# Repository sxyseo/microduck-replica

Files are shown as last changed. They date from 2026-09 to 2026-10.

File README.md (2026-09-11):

# Microduck 复刻

**简体中文** · [English](README.en.md)

> 对 [Pollen Robotics Microduck](https://pollen-robotics.com/microduck/) 的第三方复刻研究。
> 从官方公开的 MJCF 仿真模型反推出**装配图、爆炸图和可直接导入 CAD 的装配体**。

Microduck 是一只 25cm 高、737g 的双足机器鸭，15 个 Dynamixel XL330 舵机（14 个受策略控制），用强化学习走路。
它的**软件开源（Apache-2.0）**。硬件是**部分开源**：

- ✅ **RPI Robot HAT 板完整开源** —— 见 [`pollen-robotics/elec_RPI_Robot_HAT`](https://github.com/pollen-robotics/elec_RPI_Robot_HAT)（Apache-2.0）：
  KiCad 9 工程、Gerber、BOM、贴片坐标、STEP 一应俱全。这块板**不需要自己画**。
- ❌ **`imu_to_dxl` 板未开源** —— 全网无公开工程，本仓库的逆向是目前唯一公开重建。
- ❌ **机械件无可编辑 CAD**、无 BOM、无装配文档。

> 📌 **勘误（2026-09-03）**：本文档此前写作「硬件不开源、没有 PCB 原理图」，**这是错的**。
> 当时只检索了 `pollen-robotics/microduck` 主仓，未翻查该组织下以 `elec_` 开头的硬件仓库。

但官方在 `microduck_rl` 里发布了完整的 **MJCF 仿真模型 + 47 个 STL 网格**。
MJCF 里包含了完整的运动学树：每个零件挂在谁身上、相对位置精确到 0.1mm、
绕哪根轴转、行程多少、质量和惯量张量。

**这些信息足以还原出装配关系。** 本仓库就是把它还原出来的结果。

---

## 交流群

有人在做同样的事，凑了个微信群一起讨论复刻进度、踩过的坑、元件采购。

**一群、二群、三群都已满 200 人**（微信满 200 后无法扫码进），下面是**四群**的码。

<div align="center">
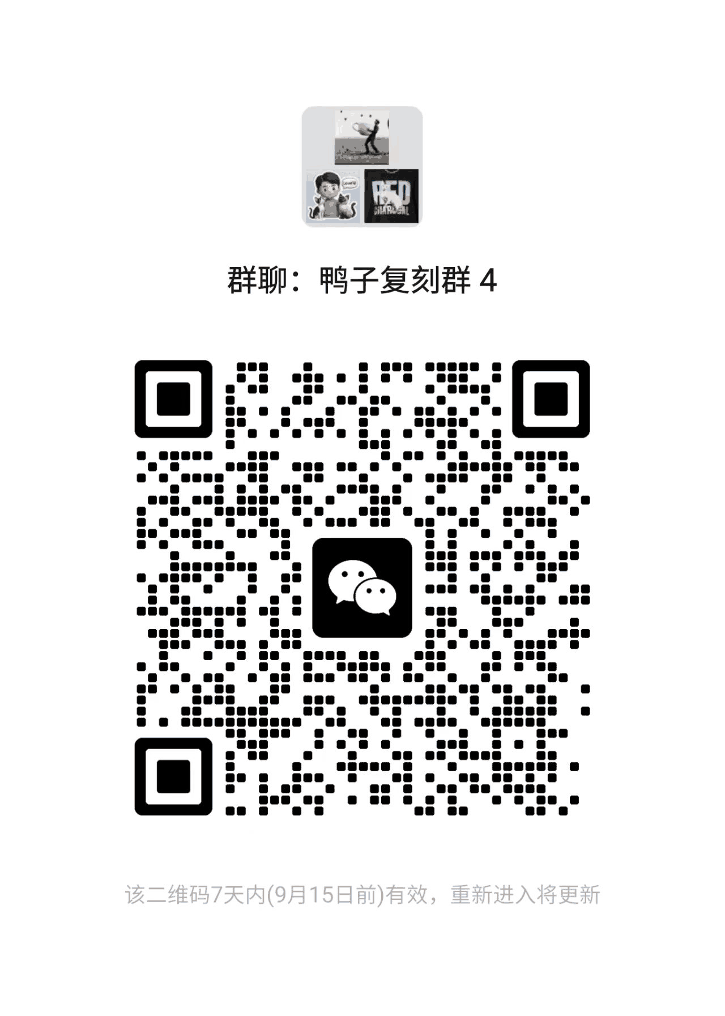
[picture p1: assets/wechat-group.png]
鸭子复刻 微信群
  
  <br>
  <sub><b>鸭子复刻群 4 · 二维码有效期到 2026-09-15</b>（微信群码 7 天自动失效）<br>
  过期了请开个 <a href="https://github.com/fanhao375/microduck-replica/issues">issue</a> 说一声，我会换上新的</sub>
</div>

## 最近更新

<table>
<tr>
<td width="50%" valign="top">

### 🔌 电气 · `imu_to_dxl` PCB 画完了

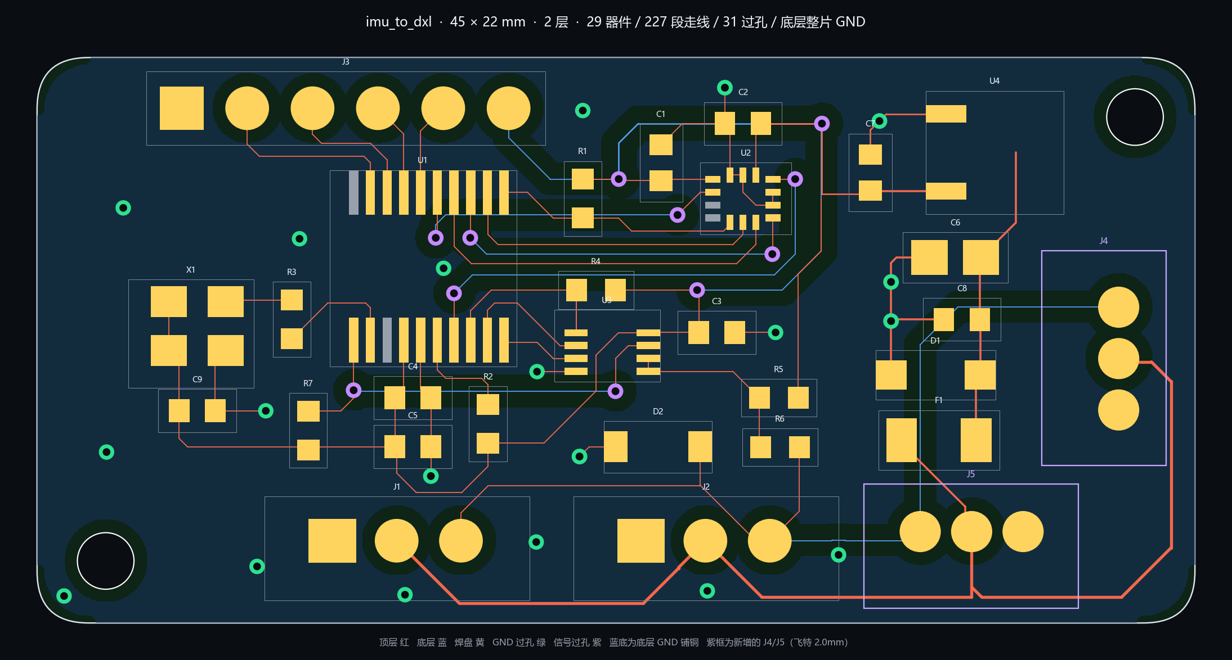
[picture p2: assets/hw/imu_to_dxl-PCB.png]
imu_to_dxl PCB 顶层装配图


官方唯一**没有开源**的那块板，第三方复刻版从原理图一路做到了 PCB。
STM32G031F8P6 + LSM6DSV16X + 半双工缓冲，作为**第 16 个设备**挂在舵机总线上。

**45 × 22 mm，2 层板**，四角 R2 圆角，两个对角 M2 孔；底层整片 GND。
23 个网络全部连通，**DRC 0 违规**，每个芯片电源脚 2.3 mm 内都有去耦。
仍然**没打样、没有实物验证**。

**[设计说明 · 评审要点 · 复查结果](hardware/imu_to_dxl/)**　·　
[原理图 PDF](hardware/imu_to_dxl/imu_to_dxl-原理图.pdf)　·　
[PCB PDF](hardware/imu_to_dxl/imu_to_dxl-PCB.pdf)　·　
[3D STEP](hardware/imu_to_dxl/imu_to_dxl-PCB.step)　·　
[接线表](hardware/imu_to_dxl/imu_to_dxl-接线表.md)　·　
[嘉立创工程](hardware/imu_to_dxl/imu_to_dxl.eprj2)

</td>
<td width="50%" valign="top">

### 🔨 机械 · 首批打印件

<a href="构建日志.md">首批打印件</a>

**有人正在把它真的做出来。** 头壳、躯干壳、腿部结构件和脚已经打印出来，
**腿部件上的 M2 螺丝已经装进去了** —— [紧固件反推](docs/紧固件反推.md)
的结论在实物上成立。

仓库其余部分都是从 MJCF 与源码反推的**纸上分析**，
构建日志记录的是**动手做的过程**：打印参数、装配问题，
以及那些反推数据在实物上到底对不对。

**[构建日志](构建日志.md)**　·　
[打印件清单](print/)　·　
[装配爆炸图](assembly-drawings/)

</td>
</tr>
</table>

> **原理图求评审** —— 特别想听这几处的意见：半双工缓冲的使能逻辑（`2OE` 接常高、
> 发送时有回显 vs 也接 DE、发送时 RX 悬空）；J1/J2 直通的铜皮宽度；
> 不上晶振（TSSOP-20 没引出 `OSC_OUT`，HSI16 跑 1 Mbps 余量够不够）。
> 发现问题请开 [issue](https://github.com/fanhao375/microduck-replica/issues)，或者在上面的群里说。

---

## 🔨 实物进度

> 本仓库反复强调「仿真 STL 不是可打印工程件」。**构建日志就是在验证这句话。**
> 结论会如实记录，无论正反。

**→ [构建日志](构建日志.md)**

---

## 装配爆炸图

爆炸图

`assembly-drawings/` 下共 7 张：

| 文件 | 内容 |
|---|---|
| `01_正面` `02_侧面` `03_背面` `04_四分之三` | 装配完成态，原色 |
| **`05_爆炸图_侧面`** | 15 个部件沿运动链炸开，标注名称与质量 |
| **`06_爆炸图_四分之三`** | 立体视角，可看清左右腿镜像关系 |
| `07_分色对照_装配态` | 与爆炸图同配色的装配完成态，对照用 |

## 装配结构

```
躯干主体 199g
├─ 左髋 yaw→roll 23g → 左髋 roll 6g → 左大腿 48g → 左小腿 22g → 左踝+脚 30g
├─ 颈根 37g → 颈俯仰件 6g → 头 yaw/roll 机构 49g → 头部总成+喙 189g
└─ 右髋 yaw→roll 23g → 右髋 roll 6g → 右大腿 48g → 右小腿 22g → 右踝+脚 30g

整机 737.2g   外形 144 × 141 × 264 mm
```

躯干和头几乎一样重（199g vs 189g）——**头部占整机四分之一，重心很高**，
这解释了为什么它的行走策略难训。

## 关节参数

每条腿 5 个自由度，头颈 4 个 —— **14 个受控**。
整机实际装 **15 个 Dynamixel XL330**：第 15 个驱动喙/下颚，走被动连杆，不进动作空间。

| 关节 | 行程 |
|---|---|
| `hip_yaw` | -25° ~ +30° |
| `hip_roll` | ±22° |
| `hip_pitch` / `knee` / `ankle` / `head_pitch` | ±90° |
| `neck_pitch` | -90° ~ +60° |
| `head_yaw` | ±170° |
| `head_roll` | ±25° |

## 📋 物料清单（BOM）

**要买什么、买几个** —— [`BOM.md`](BOM.md)

整机 15 个舵机、14 个轴承、约 325 件紧固件、2 块要打样的电路板，数量取自上游 MJCF 的
引用计数（38 种网格 / 75 个实例），不是估的。含每块板的器件清单与立创编号。

> ⚠️ 里面有两条会让人买错的更正：**电池是 NP-F550 不是 F970**、**XL330 被超压运行**。

## 3D 打印件

整机全部 STL 单件，按「要打印 / 买现成的」分好类，中英双语命名 —— [`print/`](print/)

| 目录 | 数量 |
|---|---|
| [`print/打印件/`](print/打印件/) | **30 种 / 41 件**结构件 |
| [`print/标准件-无需打印/`](print/标准件-无需打印/) | **9 个**外购件模型（对位用） |

> 上游的 XL330 台架测试夹具在另一个目录，本来就不属于机器人。打印建议与数量表见 [`print/README.md`](print/README.md)，采购见 [机械采购清单](docs/机械采购清单.md)。

## CAD 装配体

`cad/` 下是**已应用世界变换**的 STL —— 直接导入 CAD 就是装好的样子，
不用自己摆位置（上游那 47 个 STL 都是零件自身坐标系的，直接导入会全部堆在原点）。

- `00_Microduck_整机装配体.stl` —— 整机单文件，796792 三角面
- `01` ~ `15` —— 按刚体分组的 15 个部件，文件名即部件名
- `零件对照表.json` —— 每个部件由哪些上游源网格组成

单位 **毫米**。可直接用 FreeCAD / Fusion 360 / SolidWorks / Blender / 各类切片软件打开。

---

## 从运行时反推出的电控方案

<div align="center">
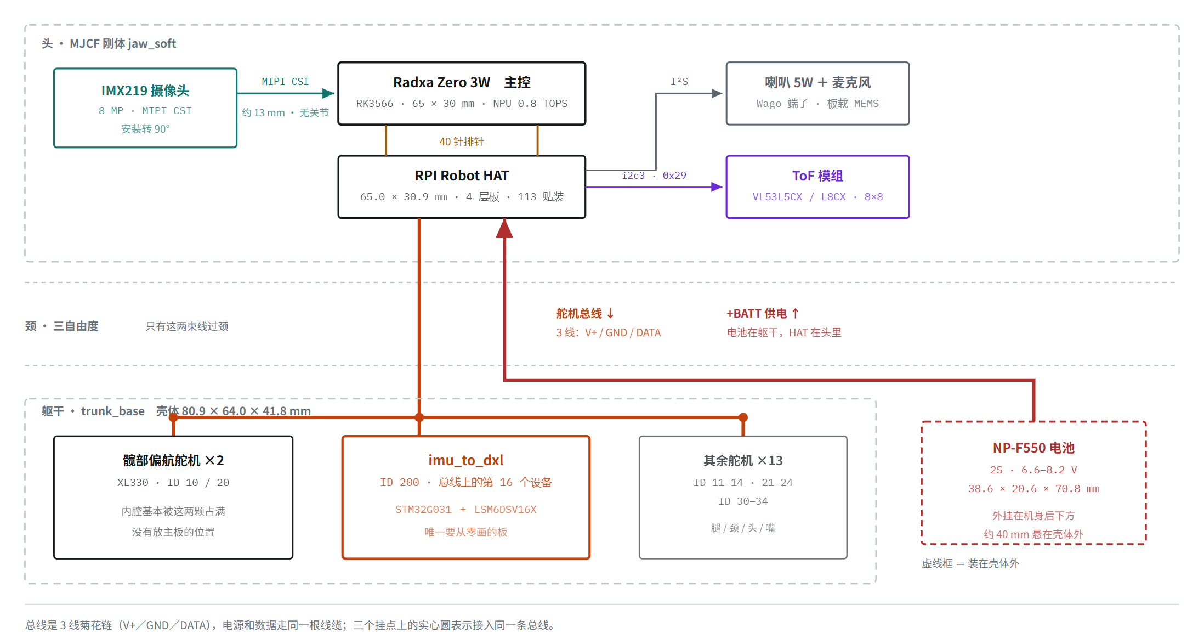
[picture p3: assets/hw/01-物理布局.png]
Microduck 电控总览：板子都装在哪
  
  <br>
  <sub><b>五个模块的物理布局</b> —— 灰色虚线框是物理区域，实线框是模块，红色虚线框表示装在壳体<b>外面</b>。<br>
  <b>橙色</b>是舵机总线（自上而下），<b>红色</b>是电池供电（自下而上）。<br>
  最容易搞错的一条：<b>主控、HAT、摄像头三者都在头里</b>，摄像头距主控板中心约 13 mm 且中间没有关节 ——<br>
  所以 MIPI 排线不穿过脖子，真正过颈的是舵机总线和供电线。<br>
  <a href="docs/硬件入门.md">完整图集与讲解 →</a>　·　<a href="assets/hw/Microduck硬件图集.pdf">下载 PDF 图集（7 张，A3）</a></sub>
</div>

**一条 1 Mbps 的 TTL 串行总线搞定一切。**

```
                Radxa Zero 3W (RK3566) · Armbian
                  ├── UART2  1 Mbps TTL 单线半双工 ── 15× XL330 + imu_to_dxl (ID 200)
                  ├── I2C3   400 kHz (pin 3/5) ────── AIC3104@0x18 · ToF@0x29 · BMI088（未用）
                  ├── I2S3   12.288 MHz ───────────── 音频
                  ├── MIPI CSI ────────────────────── IMX219（I2C@0x10，转 90°）
                  ├── 蓝牙 ────────────────────────── 手柄 / 手机 App
                  ├── Wi-Fi ───────────────────────── WebRTC
                  └── USB-C ───────────────────────── 供电 + maskrom
```

| | |
|---|---|
| **主控** | **Radxa Zero 3W** —— 市售模块，**不是定制载板** |
| SoC | RK3566，四核 Cortex-A55，Mali-G52，0.8 TOPS NPU。官方公布 1 GB / 32 GB eMMC；复刻建议 2G/16G，见 [电控采购清单](docs/电控采购清单.md) |
| **舵机总线** | **单线半双工 TTL** —— **不是** RS-232，**也不是** RS-485。Dynamixel Protocol V2 @ 1 Mbps，走 `/dev/ttyS2` |
| **自制板 1** | **`imu_to_dxl` v2** —— 一颗会说 Dynamixel 的 LSM6DSV16X：总线 ID 200、寄存器 124，12 字节块在**同一次** `sync_read` 里和舵机一起读回 |
| **自制板 2** | **RPI Robot HAT** —— TLV320AIC3104 @ 0x18、一颗休眠的 BMI088、接 ToF 的 Stemma 座。**官方已开源**（[`elec_RPI_Robot_HAT`](https://github.com/pollen-robotics/elec_RPI_Robot_HAT)） |
| 电池 | 索尼 NP-F550，2S 锂电。**没有电量计，也没有 ADC** —— 电池电压是**读舵机上报的自身供电电压**得来的 |
| 传感器 | LSM6DSV16X IMU · VL53L5CX/L8CX 8×8 ToF · IMX219（树莓派 Camera v2） |

`imu_to_dxl` 是整套设计里最漂亮的一手：**IMU 不走 I²C**，而是把自己伪装成一个 Dynamixel 从机，
于是姿态数据和关节状态在同一次总线事务里回来 —— 不需要第二条总线，主机也不用跑姿态融合
（LSM6DSV16X 的片上 SFLP 块直接输出游戏旋转四元数，还自己估计陀螺零偏）。

**完整细节：** [硬件方案逆向](docs/硬件方案逆向.md) · [硬件规格速查](docs/硬件规格速查.md)

---

## 可行性：能造出来吗

**整机可复刻，卡点在成本不在技术。** 现状：

| 项目 | 状态 |
|---|---|
| 零件几何 | ✅ 47 个 STL |
| 装配关系 | ✅ 精确到 0.1mm，已出图 |
| 关节轴线 / 行程 | ✅ 14 个全有 |
| 质量 / 惯量 | ✅ 15 个刚体全有 |
| 舵机型号 | ✅ Dynamixel XL330 ×15 → [docs/执行器选型.md](docs/执行器选型.md) |
| 轴承 | ✅ Ø22×16×4 与 Ø15×10×3 |
| **HAT 板** | ✅ **官方 KiCad + Gerber + BOM 已开源**，直接打样 → [`elec_RPI_Robot_HAT`](https://github.com/pollen-robotics/elec_RPI_Robot_HAT) |
| **`imu_to_dxl` 板** | ⚠️ 未开源，需自绘；协议与寄存器布局已完整还原 → [docs/硬件方案逆向.md](docs/硬件方案逆向.md) |
| 主控 | ✅ **Radxa Zero 3W，市售模块**（此前误判为定制载板） |
| **紧固件清单** | ✅ 已从 STL 孔位反推 → [docs/紧固件反推.md](docs/紧固件反推.md) |
| 电池 / 传感器 | ✅ **NP-F550** 2S、IMX219、VL53L8CX、LSM6DSV16X |
| **走线方案** | ❌ 无 |
| **控制软件** | ✅ 主控用同款 Radxa Zero 3W 即可直接跑（Apache-2.0）；换主控才需移植 |
| **官方策略 ONNX** | ✅ 硬件保持同款即可直接用（9 个）；改动本体或电控才需重训 |

⚠️ **仿真 STL ≠ 可打印工程件。** 仿真只关心外形与惯量，不保证配合公差、
螺纹孔、热熔螺母座和走线空间。直接打印大概率装不起来，需要自行补充工程细节。

💰 **自己造大概率比买贵，但差多少全看渠道。** 15 个 XL330 在 ROBOTIS 国际站约 **$359**、
美国站 **$412**、欧洲含税 **€603–629** —— 也就是从「略低于整机售价」到「远超」都有可能。
加上主控、电池、两块板打样和打印耗材必然更贵。完整核价见 [BOM.md](BOM.md)。

## 现实路径

放弃 100% 复刻（`imu_to_dxl` 板与可编辑机械 CAD 未开源），改成**机械照抄 + 电控自建**：

| | 方案 |
|---|---|
| 机械 | 用本仓库的 STL 与装配图，几何完全照抄 |
| 舵机 | XL330 × 15，市售件照买 |
| 主控 | **Radxa Zero 3W**，市售模块，与官方同款 |
| IMU 板 | 自己画 `imu_to_dxl`：LSM6DSV16X + MCU + 半双工收发器，协议已还原 |
| HAT 板 | **官方 Gerber 直接打样**（4 层板）。不要录音可整块省略，但**半双工方向电路要另配转接板**，见 [电控采购清单](docs/电控采购清单.md#六两块-pcb) |
| 软件 | 主控同款则官方 Rust 运行时可直接跑（Apache-2.0） |
| 策略 | 官方 9 个 ONNX 可用；改硬件后用 [microduck_rl](https://github.com/pollen-robotics/microduck_rl) 重训 |

**结论已从「机械可抄、电控是硬墙」修正为「整机可复刻」** ——
主控是市售模块，自制板的功能和协议已从源码完整还原。
详见 [docs/硬件方案逆向.md](docs/硬件方案逆向.md)。

---

## 三个必踩的坑

1. **Armbian 默认在 UART2 上跑登录控制台。** `serial-getty@ttyS2` 占着串口，
   必须 `systemctl mask` 掉。Pollen 是用 `fuser -v /dev/ttyS2` 查出来的。
2. **i2c3 和 FUSB302 抢引脚。** 用排针 pin 3/5 的硬件 I²C，代价是**失去 USB-C PD 协商**
   （普通 5V 充电仍然可用）。
3. **NPU 出厂是关的。** Armbian 默认禁用，要跑 RKNN 模型得刷 overlay 并重启。

---

## 生态导航

Microduck 的东西散在 GitHub 多个组织和 HuggingFace 三种资源里，**官方硬件仓库尤其容易漏**。
[`docs/生态导航.md`](docs/生态导航.md) 把官方仓库、模拟器、策略模型、数据集、社区项目
逐个标注了「是什么、能拿来干嘛」。

## 深入文档

| 文档 | 内容 |
|---|---|
| [紧固件反推](docs/紧固件反推.md)（[English](docs/fastener-reconstruction.en.md)） | 从 47 个 STL 扫描孔特征，反推出 M2 螺丝系统与采购量 |
| [执行器选型](docs/执行器选型.md)（[English](docs/actuator-selection.en.md)） | XL330 参数、BAM M6 配置、5 组标定 PD、回差建模；**为什么不能换闭环步进、换 STS3215 会怎样**（737g vs 2107g 实测对照）、**同级别舵机横向对比**（含宇树 S288 深度评估） |
| [**硬件入门**](docs/硬件入门.md) | **一块板一块板讲清楚** —— 五个模块各自干嘛、一个 tick 里信号怎么流、走飞特路线哪些会变，末尾附「复刻前必做的五件核对」 |
| [**硬件规格速查**](docs/硬件规格速查.md) | **一页纸规格表** —— 系统框图、芯片型号、总线参数、复刻清单、必踩的坑 |
| [硬件方案逆向](docs/硬件方案逆向.md) | 完整推导过程与证据出处（[English](docs/hardware-teardown.en.md)） |
| [**电控采购清单**](docs/电控采购清单.md) | **淘宝实链** —— 主控 / 摄像头 / ToF / 电源 / 两块 PCB / 线材与调试板，含选型推算与避坑（2026-09-04 快照） |
| [**机械采购清单**](docs/机械采购清单.md) | **淘宝实链** —— 轴承 / M2 紧固件 / 热熔螺母与压头 / 螺纹胶 / 耗材 |
| [**训练参数调整与新动作开发指南**](docs/训练参数调整与新动作开发指南.md) | 面向新手的分阶段路线；按目标查训练参数，覆盖走路、跑步、舞蹈、换舵机、导出与真机验证 |
| [社区动态](docs/社区动态.md) | X / GitHub 情报，含外部验证、噪音与风险提示 |

结论速览：**整机是 M2 螺丝系统**（Ø2.2 过孔 ×77 + Ø4.4 沉头孔 ×28 + Ø1.6 攻丝底孔 ×20），
结构件过孔约 146 个；轴承 Ø22×16×4 与 Ø15×10×3。

---

## 重现

```bash
# 1. 拉上游仓库（源码与仿真资产不重复托管，打印件除外 —— 见 NOTICE.md）
bash scripts/fetch_upstream.sh

# 2. 重新生成装配图
python scripts/render_assembly.py upstream/microduck_rl assembly-drawings

# 3. 重新导出 CAD 装配体
python scripts/export_assembly_stl.py upstream/microduck_rl cad

# 4. 重新扫描孔特征
python scripts/analyze_holes.py upstream/microduck_rl/src/mjlab_microduck/robot/microduck/assets
```

依赖：`mujoco` `numpy` `pillow` `scipy`。渲染需要可用的 OpenGL 上下文。

---

## 许可证

- `scripts/` —— Apache-2.0
- `assembly-drawings/` `cad/` —— **CC BY-SA-NC 4.0**（上游 3D 模型为 CC BY-SA-NC，
  依 ShareAlike 条款衍生作品须沿用同协议，**不得商用**）

详见 [NOTICE.md](NOTICE.md)。本项目与 Pollen Robotics 无隶属关系，未获其背书。

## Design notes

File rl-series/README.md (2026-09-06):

# rl-series · MicroDuck RL 公众号系列工作区

> **源码拆解 + 可复现实验 + 复刻过程**。不做代码翻译，每篇文章讲一个
> 「我改了什么 → 为什么改 → 怎么运行 → 指标如何变化 → 结论和失败原因」的完整故事。

## 诚实性三标签（每篇必带）

- **【已验证】** 我实际运行过，附命令与产物路径
- **【推测】** 根据代码/注释推断，明确说出依据
- **【未完成】** 还没有验证，写明计划何时验证

## 目录

```
rl-series/
├── 30天计划.md            ← 总纲：日历 + 主链路 + 每周退出标准
├── articles/              ← 12 篇（01–06、10 可发布/近可发布，其余框架稿）
├── experiments/
│   ├── TEMPLATE.md        ← 实验记录模板（预注册假设）
│   ├── exp000-*.md        ← 已完成：5 迭代冒烟，真实指标已入库
│   └── exp001-imu-randomization/  ← 待执行：A/B 一行补丁 + 脚本 + 记录表
├── scripts/               ← 全部可复跑：指标提取 / A-B 出图 / ONNX 验形状 /
│                             flags 导出 / 渲染封面 / obs 布局图
└── assets/                ← 已生成资产 + 待截清单（截图清单.md）
```

## 快速开始（对应 30 天计划 D1–D4）

```bash
cd upstream/microduck_rl
uv run list-envs                                   # 环境自检
uv run train Mjlab-Velocity-Flat-MicroDuck \
    --env.scene.num-envs 64 --agent.max_iterations 5   # 冒烟（AGENTS.md 官方写法）
uv run tensorboard --logdir logs/rsl_rl
```

已验证事实速览（上游 `29e887e`，本机 Mac mini 实测）：

- 训练/回放/导出链路全通；lesson-01（5 迭代 ×8 env）reward `-0.061 → 0.095`，`fell_over ≈ 1.0`（还不会走，真实且诚实）。
- **exp001 A/B + exp001b 扰动测试全部实跑完成**（`experiments/exp001-imu-randomization/`）；
  **3D 回放已通**：`scripts/capture_rollout.py` 离屏渲染 GIF + 关键帧（`assets/回放-*.gif`）。
- ONNX 输入 `obs[1,61]` / 输出 `actions[1,14]`；Rust 运行时同款布局 `3+3+14+14+14+13=61`；
  本机评估时网络结构实证 critic 输入 76 维。
- 本系列所有脚本只依赖 `upstream/microduck_rl/.venv`（tensorboard/matplotlib/onnx/mujoco），无需 GPU。

## 3D 仿真怎么看

```bash
cd upstream/microduck_rl

# 离屏捕获（无窗口，产出 GIF + 关键帧到 rl-series/assets/）
CUDA_VISIBLE_DEVICES="" .venv/bin/python ../../rl-series/scripts/capture_rollout.py \
    --ckpt logs/rsl_rl/velocity/<run>/model_99.pt --label <标签>

# 交互式实时查看 —— 浏览器方案（已验证 ✓，macOS 上最稳）
CUDA_VISIBLE_DEVICES="" uv run play Mjlab-Velocity-Flat-MicroDuck \
    --checkpoint-file logs/rsl_rl/velocity/<run>/model_99.pt \
    --viewer viser --num-envs 1
# 然后浏览器打开 http://localhost:8080
```

> ⚠️ **macOS + uv 环境勿用 `--viewer native`**：MuJoCo 原生窗口要求 `mjpython`，
> 而 uv 安装的独立版 Python 与 mjpython 的动态库搜索路径不兼容（`dlopen libpython3.12.dylib`
> 失败，DYLD_LIBRARY_PATH 覆盖无效）。浏览器方案 `viser` 不经 `launch_passive`，实测可用。

## 与其他目录的关系

- `../`（microduck-replica）：机械/电控复刻研究 —— 本系列是它的「大脑」续篇
- `../../OpenMicroDuck/`：社区完全开源复刻计划 —— 文章 02 讲三者关系
- 上游 `upstream/microduck_rl`：**只读不改**；实验改动一律走 patch + 跑完还原

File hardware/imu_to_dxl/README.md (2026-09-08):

# imu_to_dxl 原理图 + PCB · 求评审

> ⚠️ **这是第三方复刻件，不是官方设计。**
> 官方从未公开这块板的原理图、Gerber 或外形（全网零命中，见
> [硬件方案逆向](../../docs/硬件方案逆向.md)）。本目录是根据 MJCF 模型、官方运行时源码
> 和已开源的 HAT 工程反推 + 自行选型的结果，**未经打样、未经实物验证**。
> 发现问题请开 [issue](https://github.com/fanhao375/microduck-replica/issues)。

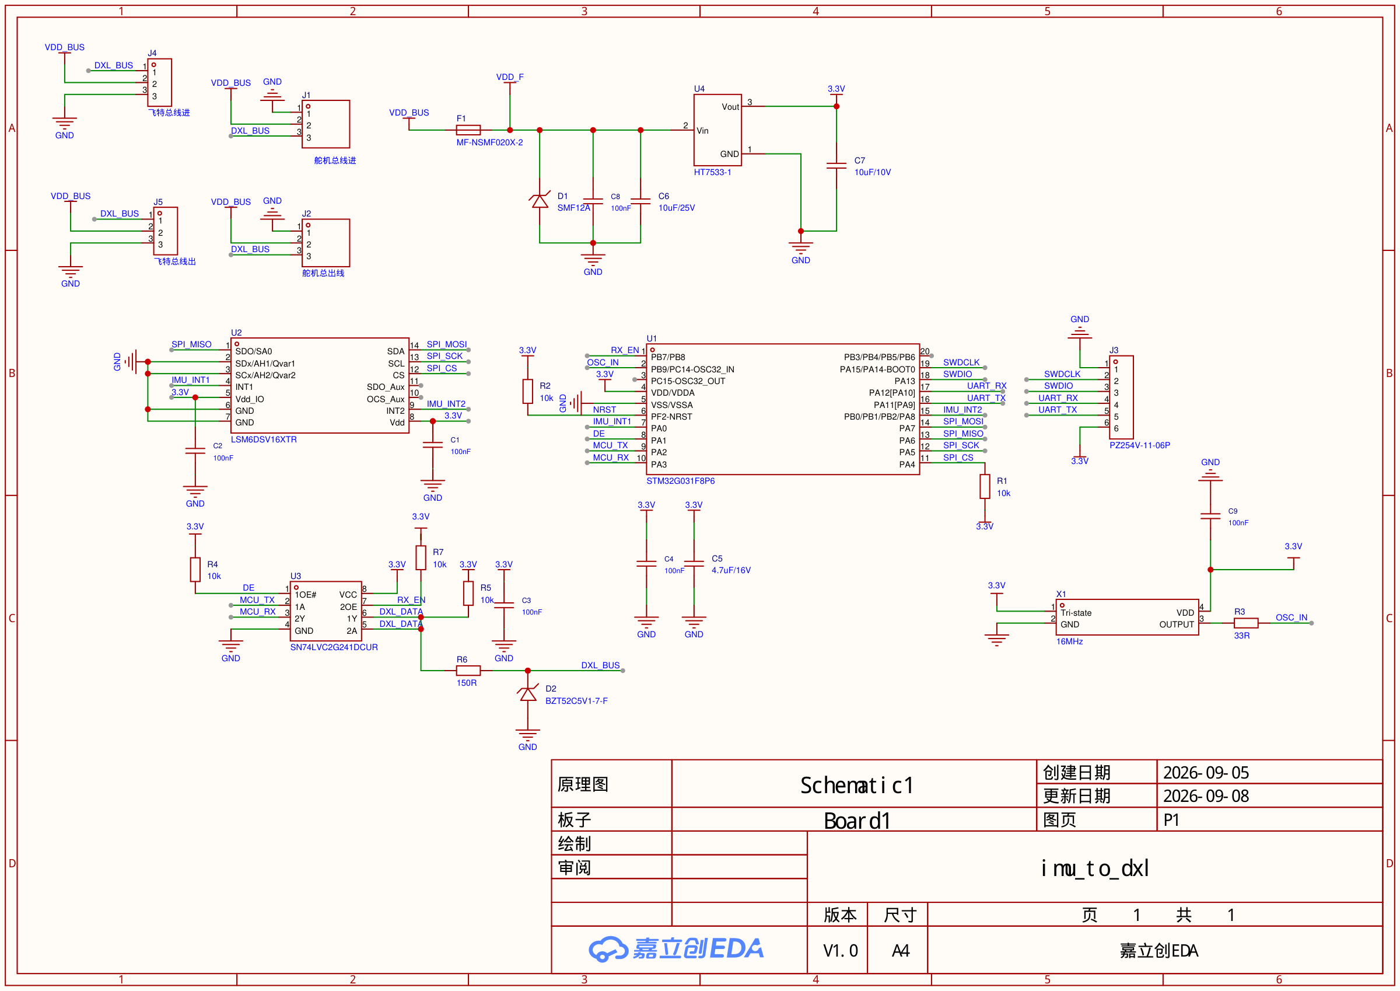
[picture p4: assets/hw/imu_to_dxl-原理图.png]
imu_to_dxl 原理图


| 文件 | 说明 |
|---|---|
| [`imu_to_dxl-原理图.pdf`](imu_to_dxl-原理图.pdf) | 矢量 PDF，放大看细节 |
| [`imu_to_dxl-接线表.md`](imu_to_dxl-接线表.md) | 逐网络列出每个引脚，可以直接对着核 |
| [`imu_to_dxl.eprj2`](imu_to_dxl.eprj2) | 嘉立创 EDA 专业版工程，可直接打开改 |
| [`../../BOM.md`](../../BOM.md) | 完整 BOM，含立创编号与每颗器件的选型理由 |

---

## 这块板干什么

官方 Microduck 的 15 个舵机挂在一条 Dynamixel 半双工总线上。这块小板
**作为第 16 个设备挂在同一条总线上**，对外表现成一个 Dynamixel 从机（ID 200），
主控用读寄存器的方式向它要姿态数据。

板上的 IMU 用的是 **LSM6DSV16X**，它片内有 **SFLP 硬件融合块**，
直接输出游戏旋转四元数 —— 姿态解算不占主控算力，也不占总线带宽。

```
主控（树莓派/泰山派）
      │  1 Mbps 半双工单线
      ├── 舵机 ×15
      └── imu_to_dxl（本板，ID 200）
             ├── LSM6DSV16X   SPI 四线 + 两路中断
             ├── STM32G031F8P6 收包 / 组包 / 读 IMU
             └── SN74LVC2G241 半双工收发缓冲
```

## 核心选型与理由

| 位号 | 器件 | 为什么选它 |
|---|---|---|
| **U1** | STM32G031F8P6 | ① USART 有**硬件 DE**（RS485 Driver Enable）—— 1 Mbps 下一个比特只有 1 µs，软件翻方向脚的抖动就在这个量级。对照：**STM32F401 手册全文没有 "Driver Enable"**，只能软件切<br>② 与 IMU 同厂，ST 的 `lsm6dsv16x-pid` 驱动和 SFLP 例程现成 |
| **U2** | LSM6DSV16XTR | 片内 SFLP 融合，直接出四元数 |
| **U3** | SN74LVC2G241DCUR | 双缓冲做单线半双工。通道 1 左进右出、通道 2 右进左出，正好对着走线。3.3 V 供电时**输入耐 5.5 V**，扛得住舵机 5 V 的信号 |
| **U4** | HT7533-1 | **耐压 30 V** —— 前两道保护都失效时它自己还活着 |
| **F1** | PPTC MF-NSMF020X-2 | **24 V / 200 mA 保持**。本板故障时先断自己，不拖垮整条舵机总线 |
| **D1** | TVS SMF12A | 截止 12 V > 满电 8.4 V，钳位 19.9 V < C6 的 25 V 耐压 |
| **C6** | 10 µF / **25 V** | 挂在 8.4 V 母线上。MLCC 有直流偏压衰减，6.3 V/10 V 的余量不够 |
| **C5** | 4.7 µF | 与 C4 的 100 nF 组成 ST 要求的组合 —— **DS12992 Rev 3, Figure 13** 对 `VDD/VDDA` 明确标注 `1 × 100 nF + 1 × 4.7 μF` |

## 几个可能有争议的决定

### 1. `2OE` 接常高，发送时会听到自己的回显

`U3.1 (1OE#)` 接 DE 控制发送缓冲，`U3.7 (2OE)` **直接接 3.3 V，接收缓冲常开**。

- 代价：发送时 MCU 会在 RX 上收到自己发的字节，固件按发送长度丢弃
- 好处：PA3 永远有人驱动，**不会悬空**

备选是 `2OE` 也接 DE（发送时关掉接收），但那样发送期间 RX 浮空，
重新使能时可能产生假起始位。我选了前者，**欢迎反驳**。

### 2. 没有晶振，只留了焊盘

TSSOP-20 封装**没有引出 `OSC_OUT`**（DS12992 Rev 3, Table 12：2 脚 `PC14` 的附加功能有
`OSC_IN`，3 脚 `PC15` 只有 `OSC32_OUT`），所以**无源晶振根本接不了**。

HSI16 精度（Table 41）：出厂 −0.75%/+0.5%，0–85 °C 温漂 ±1% → 最坏约 **−1.85%/+1.55%**。
1 Mbps 异步 UART 典型容差 ±3%，够用但余量不多。

板上留了 **X1（16 MHz 有源晶振，HSE 旁路）+ C9 + R3** 三个焊盘，**默认不贴（DNP）**。
另外固件可以用定时器输入捕获测主机来的比特周期，反调 `HSITRIM`（步进 0.2–0.4%/档），
误差能压到 0.3% 以内，不花钱。

### 3. J1 / J2 保留两个，靠铜皮解决过流

J1 和 J2 三根线一一并联。**本板若在链条中间，下游全部舵机电流都流过本板的连接器和铜箔。**

飞特 HD-1910-C001 官方参数：额定 **500 mA** / 堵转 **1.8 A**。

但这个约束**不是本板独有的** —— 舵机之间本来就是菊花链，它们自己的连接器承受同样的电流。
HAT 有 **4 个舵机接口**，15 个舵机分在 4 条支路上，每条最多 4 个，一条支路额定约 **2 A**，
在 3 A 以内。官方设计能接受，本板用同样的座子不会更差。

**所以保留两个座子**：想挂末端就不装 J2，想串中间就装上，灵活性几乎零成本。
PCB 上把 `VDD_BUS` 与 `GND` 从 J1 到 J2 走**大铜皮**（≥ 2 mm 或直接铺铜）即可。

> 曾有评审意见建议「只留一个 3P 座子」。那在本板确定是叶子节点时成立，
> 但**如果它是链条第一个节点**（HAT 出来先进本板、再出去给舵机），就必须两个。
> 官方拓扑无从确认，保留两个更稳。

### 4. 协议靠软件自动识别，没做跳线/拨码

飞特与 Dynamixel 的物理层完全相同（半双工单线 / 1 Mbps / 3 线 / GND-VCC-DATA），
差别只在包格式：

| | 包头 | 后续 | 校验 |
|---|---|---|---|
| Dynamixel V2 | `FF FF` | **`FD 00`** | CRC-16 |
| 飞特 SCS | `FF FF` | `ID` + `LENGTH` | `~(ID+LEN+INST+参数)` |

飞特官方协议文档写明 **Length = 参数个数 N + 2**，所以最小为 2、**永远不会是 0**；
ID 范围 0–253。→ `FF FF FD 00` 只可能是 V2，**判别无歧义**。

固件收前 3 包投票锁定协议，之后按锁定的收发；连续 100 包解析失败则解锁重判。
比拨码开关可靠（会走路的机器人里，拨码触点是振动失效点）。

### 5. J3 用 6P，把串口 printf 也引出来

`1=GND 2=SWDCLK 3=SWDIO 4=UART_TX 5=UART_RX 6=+3V3`，前 4 脚顺序不变，
**原来的 4 针 SWD 排线插 1–4 仍可用**。

UART 来自 U1 脚 16/17（`PA11[PA9]` / `PA12[PA10]`），经 `SYSCFG_CFGR1` 重映射成
`USART1_TX/RX`。

**不上 USB**：G031 没有 USB 外设（手册 Development support 只写 "serial wire debug (SWD)"），
加 USB 要多一颗 CH340/CP2102，45 × 22 mm 板上不划算。
调试走 SWD + RTT（`probe-rs` 支持在 CMSIS-DAP 上跑 RTT，不停 CPU）。

> Cortex-M0+ **没有 SWO/ITM**，别指望 SWO printf。

---

## 板框与安装孔

| 项 | 值 |
|---|---|
| 板框 | **45 × 22 mm**，2 层板 |
| 四角 | **R2 圆角** |
| 安装孔 | **2 × M2 非金属化孔 φ2.2 mm**，走对角 |
| 孔位（板左下角为原点） | MH1 (2.667, 2.413)、MH2 (42.672, 19.685) mm |
| 孔距 | X 向 40.00 mm ／ Y 向 17.27 mm ／ 对角 43.57 mm |
| 孔到板边 | MH1 **1.31 mm** ／ MH2 **1.22 mm**（嘉立创要求 ≥0.4 mm） |

两孔中点 (22.67, 11.05) 与板心 (22.50, 11.00) 相差 0.17 mm，**转 180° 装基本还能对上**（偏差 0.34 mm）。

> ⚠️ **孔位在 2026-09-08 改过。** 原设计是 MH1 (5.5, 3.5) / MH2 (39.5, 18.5)、X 向 34 mm，
> 刻意对齐原版 `banana_pcb_locker` 打印件的两个定位耳间距。
> **加 `J4`/`J5` 时 MH2 的让位圈正好卡住右边那条唯一能放插件的空白带**，
> 于是把两个孔都往角上挪，X 向变成 40 mm。
> **代价是不再与原锁扣通用 —— 机械侧同步改压条。**
> 反正逆向文档里「锁扣压的就是 `imu_to_dxl`」本来也只是推断
> （见 [硬件方案逆向](../../docs/硬件方案逆向.md)），硬约束只有「IMU 刚性固连在 `trunk_base` 上」这一条。

板框文件：`imu_to_dxl-板框-45x22-R2.dxf`（单位 mm，8 段闭合：4 直边 + 4 段 90° 圆弧）。

> **为什么单独给 DXF**：这版立创EDA专业版的图元接口只接受铜层，
> 往板框层（layer 11）建线/弧一律报「参数不正确」，改层、改文档源都被挡，
> 所以板框走 DXF 导入（`文件 → 导入 → DXF`，目标层选**板框层**，单位 mm，原点对齐 0,0）。
> 两个 M2 孔不在 DXF 里 —— 它们已经作为真实的 NPTH 焊盘建在 PCB 上了。

## PCB：布局与布线

imu_to_dxl PCB 顶层装配图

*布线图，由工程实测数据渲染（顶层红 / 底层蓝 / 焊盘黄 / GND 过孔绿 / 信号过孔紫，蓝底为底层 GND 铺铜，紫框为 `J4`/`J5`）。*
*状态 2026-09-08：29 器件 · 227 段走线 · 31 过孔 · 172 泪滴，含 `R7`、`J4`、`J5`，`X1`/`R3`/`C9` 已改为实贴。*
*本目录的 `.eprj2` / PCB PDF / 原理图 PDF / STEP 与 `assets/` 下两张图，**全部已更新到 2026-09-08 的最终版**。*

**45 × 22 mm，2 层板，1 oz 铜**，四角 R2 圆角，两个对角 M2 非金属化孔。
贴片件全在正面；3 个插件连接器分两条边：`J1` `J2`（舵机总线）在下边，
`J3`（SWD + 串口）在上边。

### 分区

| 区 | 内容 | 为什么 |
|---|---|---|
| 下边 | `J1` `J2` 总线连接器（JST EH 2.5 mm） | 线束从躯干走线，就近出线 |
| 右下 | **`J5` 飞特总线出**（2.0 mm） | 与 `J1`/`J2` 同侧，四个座子的 `VDD_BUS` 直通铜皮连成一条 |
| 右边缘 | **`J4` 飞特总线进**（2.0 mm） | 全板唯一放得下插件的空白带；为它让路才把 MH2 挪走的 |
| 右侧 | `F1` → `D1` → `C6`/`C8` → `U4` → `C7` | 电源链一条路走到底，跟数字区隔开 |
| 中部 | `U3` 缓冲 + `D2` 钳位 + `R6` 串阻 | 夹在 MCU 和总线连接器之间，收发路径最短 |
| 中上 | `U1` 主控、`U2` IMU 及各自去耦 | |
| 左侧 | `X1` / `R3` / `C9` 时钟位 | 已改为实贴，放在边角不占好位置 |
| 上边 | `J3` 调试排针 | 插拔方向朝外 |

### 布线

| 项 | 值 |
|---|---|
| 元件 | **29 个**（含 09-07 新增的 `R7`、09-08 新增的 `J4`/`J5`） |
| 走线 | **227 段**（顶层 197 / 底层 30） |
| 线宽 | 信号 0.25 mm 为主；**总线直通 0.76 mm** |
| 过孔 | **31 个，φ0.6 / 孔 0.3 mm** |
| 泪滴 | 172 个 |
| 铺铜 | **底层整片 GND**，顶层不铺 |

底层 30 段走线，**地平面基本完整**——这是给 SPI 和 1 Mbps 半双工总线留的回流路径。
顶层的 GND 焊盘各自就近打过孔下到地平面。

### 复查结果 · 2026-09-08

除立创自带 DRC 外，另用脚本按**真实焊盘形状**（圆形 / 跑道形 / 矩形）重新栅格化，
独立复核了一遍：

| 检查项 | 结果 |
|---|---|
| 立创 DRC | **0 违规** |
| **连接器脚序** | **四个全对**：`J1`/`J2` = `GND`/`VDD_BUS`/`DXL_BUS`；`J4`/`J5` = `DXL_BUS`/`VDD_BUS`/`GND`（**反序**，见下方脚序一节） |
| 网络连通性 | **23 个网络全部连通**（栅格连通域 + 过孔/插件孔跨层，含底层铺铜） |
| 异网最小间距 | **0.152 mm ＝ 5.98 mil**（精确几何，非栅格）。嘉立创双面板下限 0.127 mm，余量 20% |
| 铜到板边 | 最小 **0.37 mm** |
| 孔到孔（孔壁间） | 最小 **0.751 mm**，要求 ≥0.4 mm |
| 孔到板边 | MH1 **1.31 mm** / MH2 **1.22 mm** |
| M2 让位 | MH1 让位圈 2.5 mm 内只有一个 **GND** 过孔（1.81 mm）—— 螺钉压到地还是地，无害；MH2 最近 4.59 mm |
| 过孔规格 | φ0.6 / 孔 0.3 mm，符合嘉立创双面板下限 |
| 去耦距离 | `U1.4`→`C4` 2.27、`U2.8`→`C1` 2.00、`U2.5`→`C2` 2.01、`U3.8`→`C3` 1.96、`X1.1`→`C9` 2.39 mm，均 <2.4 mm；`U4.3`→`C7` 2.94 mm。⚠️ `U4.2` LDO 输入侧的 100nF `C8` 为 **6.64 mm**（偏松，但管瞬态的 10µF `C6` 在 4.29 mm，且 LDO 是线性的无开关） |

**载流核算**：四个座子之间的 `VDD_BUS` 直通链
`J1.2 → J2.2 → J5.2 → J4.2` **全程 0.76 mm**，1 oz 铜下 ΔT=10K 约 2.0 A、ΔT=30K 约 3.2 A。
JST EH 单触点额定 3 A，**走线与连接器基本同一量级**，加宽并不能抬高整条链路的上限。
另有 4.7 mm 的 0.51 mm 段在 `J1.2 → F1.1` 这条**只喂本板自己**的支路上，
前面是 200 mA 保持的 PPTC，够用。

> **2026-09-08 抓到并修掉一处**：布 `DXL_BUS` 去 `J4`/`J5` 时，有一个 φ0.3 过孔
> 落在了 `J2.3` 的 φ1.0 插件孔正上方（孔心距 0.001 mm）。立创 DRC 报
> `Hole to Hole (DXL_BUS): J2_3 ↔ e75` —— 钻孔是机械工序，同网络也不允许重叠。
> `J2.3` 本身是贯穿孔、顶底早已连通，该过孔纯属冗余，删除后连通性不变、DRC 归零。

**仍未验证**：**没有打样，没有实物**。以上全部是几何与规则层面的核对，
不能替代实测。

### 待办

- 下单前跑一次**器件标准化**（原理图 DRC 报过「元件属性与供应商编号不匹配」）
- 丝印复核：位号是否压焊盘、`U1` 一脚 / `D1` `D2` 阴极 / `J1` 一脚标记是否齐全
- **连接器高度**：`J1`/`J2`/`J3` 是 JST EH / 2.54 排针直插，本体约 **8 mm**。若躯干内腔
  确实只有 6.65 mm，需换卧式 `S3B-EH-A`，封装与 BOM 都要跟着改 —— 用导出的 STEP 在
  装配体里比一下即可定论。
  **`J4`/`J5` 反而不用担心**：`B3B-PH-K-S` 本体约 **6.0 mm**，塞得进 6.65 mm 的内腔
- **板端座子型号待确认**：飞特规格书只写了线端是 `AMP2.0-3P`，**板端型号没给**。
  本板暂用 `B3B-PH-K-S`（JST PH，2.0 mm 立式）。焊盘阵是三孔 2.0 mm 间距，
  与其它 2.0 mm 系列通用，**将来换系列只改封装、不动焊盘、不重布线**
- **下单前重导生产文件** —— 器件从 27 变 29，立创那边的 Gerber / BOM / 贴片坐标都要重传

## 想请你重点看这几处

1. **`2OE` 常开这个取舍**（上面第 1 条）—— 回显 vs RX 悬空，哪个更糟
2. **J1/J2 过流与铜皮宽度**（第 3 条）—— 2 mm 够不够
3. **HSI16 跑 1 Mbps 的余量**（第 2 条）—— 有实测经验的说一声
4. **三道过压防线够不够** —— 8.4 V 母线 + 舵机反电动势
5. **连接器**：见下方「⚠️ 飞特脚序按型号不同，而且是反的」。`J4`/`J5` 两个 2.0 mm 座子
   已在原理图与 PCB 上落位（2026-09-08），但**板端座子的确切系列还没拿实物比过**
   —— 飞特规格书只写了线端 `AMP2.0-3P`，板端型号待厂家确认

## ⚠️ 飞特脚序按型号不同，而且是反的

**这是本板最容易致命的一处，两份厂家规格书各自都没错 —— 是两个型号真的相反。**

| | 连接器 | 脚 1 | 脚 2 | 脚 3 |
|---|---|---|---|---|
| **`HD-1910-C001`**（本仓库选用） | **`AMP2.0-3P`**（2.0 mm） | **Signal/TTL** | Vcc | **GND** |
| `HL-2915-C002`（另一型号，勿照抄） | `AMP-3` | **GND** | Vcc | **Signal/TTL** |
| 本板 `J1`/`J2`（JST EH 2.5 mm，同官方 HAT） | `B3B-EH-A` | GND | VDD_BUS | DXL_BUS |
| 本板 `J4`/`J5`（2.0 mm，对口飞特） | `B3B-PH-K-S` | **DXL_BUS** | VDD_BUS | **GND** |

四个座子的脚序已从 PCB 网表反读复核过，全部落对（2026-09-08）。
**两种间距插不进对方（2.0 vs 2.5 mm），物理上杜绝了插错，只剩「画错」这一种可能。**

出处：飞特《HD-1910-C001 串型规格书》**A/0，2026-09-07** 第 3/7 页 6-7 项；
飞特《HL-2915-C002 串型规格书》A/0，2026-02-27 第 4/8 页 6-7 项。
两份都是厂家发给客户确认的规格书，**本仓库按惯例不转载 PDF**，需要请向飞特索取。

> 本仓库此前只记了 `HL-2915` 那一行、却推荐 `HD-1910` 作为替代型号，**是个坑**，
> 2026-09-08 按 A/0 新规格书更正。
>
> ⚠️ **`HL-2915-C002` 是 9–14 V（典型 12 V）舵机，挂不上本方案的 2S 母线（6.6–8.2 V）**
> —— 它 9 V 才开始工作。当初拿它当「飞特接口惯例」的样本是权宜之计，别照着选型。
>
> ⚠️ **间距也对不上**：`AMP2.0` 是 2.0 mm，`JST EH` 是 2.5 mm，**插不进对方**。
> 好在这一点反而是保险 —— 物理上杜绝了插错，只剩「画错」这一种可能。

## 已确认 / 未验证

**已确认（一手资料）**

- **HD-1910-C001** 接口 `1=Signal/TTL · 2=Vcc · 3=GND`，连接器 `AMP2.0-3P`，线长 15±0.5 cm
  —— 飞特《HD-1910-C001 串型规格书》A/0 (2026-09-07) 第 3/7 页 6-7 项
- HD-1910-C001 走 **TTL 三针总线**，**4–8.4 V**，堵转 9/12/15 kg·cm @4.8/6/7.4 V，
  额定电流 **500/690/900 mA**，堵转电流 **1.2/1.6/2.0 A**，静态 20 mA，12 bit 磁编码，
  减速比 1/320 —— 同上规格书第 2/7、3/7 页
- **电机自带三道电子保护**（同上第 4/7 页 7-11）：
  **过流**（>0.5 A 持续 2 s 关输出，阈值与时长可自定义，**出厂默认关闭**）·
  **过压**（>10 V 或 <4 V 保护，范围可自定义，**出厂默认关闭**）·
  **过热**（>80 ℃ 关扭矩输出，**出厂默认开启**）。
  **装机前应把前两条打开** —— 异常检测在电机里做，主机不必轮询
- 反馈六项齐全：输入电压 / 负载 / 工作电流 / 工作速度 / 工作温度 / 位置（同上 7-10）。
  官方运行时确实在用：`present_current` 每 tick 随位置一起读，电压+温度约每秒一次，
  且**电压是整机唯一的电池计量手段**（`duck-control/src/{bus,model}.rs`）
- 出厂默认运行模式是**模式 4「纯位置 PD（Sim2Real）」**，正对强化学习落地（同上 7-12）
- 包格式、`Length = N+2`、校验算法、同步读 `0x82` —— 飞特官方《舵机SCS通信协议》
- 包格式、`Length = N+2`、校验算法、同步读 `0x82` —— 飞特官方《舵机SCS通信协议》
- STM32G031 无 HSE 引脚、HSI16 精度、`100 nF + 4.7 µF` 去耦要求 —— ST DS12992 Rev 3
- 原理图连通性 —— 已用脚本逐网络核对，无悬空脚、无短路、无重名网络

**未验证**

- **整块板没打样过**，没有实物
- 板框 45 × 22 mm 与 M2 孔 X 向 34 mm 间距是从打印件 `banana_pcb_locker` 反推的，非官方尺寸
- MCU 型号是本仓库的选型建议，**不是逆向所得** —— 官方那块板用什么 MCU 无从还原

---

## 评审记录

### 2026-09-07 · 三条布局/选型建议（都不采纳，理由记下来）

评审人看了图纸提了三条：阻容换 0402、IMU 放板心、LDO 远离 IMU。逐条量了数据，
**结论是维持现状**，但每条的理由值得记下来 —— 尤其第二、三条其实指向同一件事。

**① 阻容换 0402 —— 不换，理由不在「能不能手焊」**

对方补充说「别折腾自己焊接，团一下上立创贴片省心」。这个建议本身对，但换不换 0402
的判据不在这儿：本目录 2026-09-06 那条记录第一句就写了「**理由不是 0402 手焊不了**」
—— 板上有 LGA-14 的 LSM6DSV16X（底部焊盘 3×2.5 mm），本来就必须上热风。

真正的理由是**调试期返修**：`R6` 串阻要从 150 Ω 试到 33 Ω、上拉可能要摘、去耦可能要补。
**第一版没验证过的板子必然要改几次**，这一点不因为找立创贴片而改变 —— 贴片厂只负责
第一次，改还是得自己动烙铁。

代价那边：16 个阻容换 0402 省 **12.5 mm²，占板面积的 1.3%**，而这块板**只用了 36%
的面积**，根本不缺地方。0402 的 10k/100nF 在立创同样是基础库，省料费这条对两边都成立、
不构成理由。

**② IMU 放板心 · ③ LDO 远离 IMU —— 方向都对，但量级不同**

先量数：

```
板心 (22.5, 11.0) = 两个 M2 孔的中点（当初就是这么设计的）
U2 (IMU)  离板心 7.47 mm，离两螺钉连线 3.00 mm
U3 (缓冲) 离板心 0.41 mm      ← 最刚的位置被逻辑芯片占了
U2 ↔ U4 (LDO) 中心距 6.37 mm
```

**热的量级**：板上总电流约 5–10 mA（G031 约 3 mA + LSM6DSV16X 约 0.65 mA + 缓冲约 1 mA
+ 上拉），LDO 压降 8.4 − 3.3 = 5.1 V → **耗散约 51 mW**（满电最坏）。SOT-89 在小铜箔上
θJA 约 100–160 °C/W → 结温升 **5–7 °C**；隔 6.4 mm、中间一整片底层地铜散热，传到 IMU
处**温差约 1–3 °C**。LSM6DSV16X 陀螺零偏温漂约 0.05 °/s/°C → **约 0.1 °/s 偏置**。
走路时陀螺是几十 °/s 量级，且躯干里 15 个舵机吃安培级电流，热源比 51 mW 大两三个数量级。
**方向对，但不是主导项。**

**真正值得动的是第②条的另一面**：板心正好是两螺钉中点，是全板最不易形变的位置，
而现在坐在那儿的是不在乎位置的 `U3`。把 `U2`/`U3` 对调可一箭三雕 ——
IMU 离板心 7.47 → 0.4 mm，同时离 LDO 6.37 → **11.3 mm**（翻倍）。

**为什么这次仍不动**：板子已 DRC 0 违规、全部布通；对调意味着中间区域重排 + 重布
SPI×4、2 个中断、缓冲的 DE/TX/RX/DXL_DATA。按上面的量级估算，收益是"更稳妥"而非
"解决已知问题"。**留到打样后拿实测数据再决定** —— 若实测陀螺零偏随 LDO 负载明显漂移，
或振动噪声偏大，v2 一并改。

**一个更重要的提醒**：IMU 在**机器人里**的位置与朝向是训练模型定死的，比它在板上偏
7 mm 重要得多。那个由板子怎么装进躯干决定，已查证并记在
[`docs/硬件方案逆向.md`](../../docs/硬件方案逆向.md)：`trunk = [+raw_z, +raw_y, −raw_x]`，
绕 Y 轴 +90°。板上挪位置不影响这条。

### 2026-09-07 · 给 `2OE` 留一根控制线（R7 + RX_EN）

有人建议把「那个 EN 脚」预留一根线到 MCU。指的是 `U3.7 (2OE)` —— 接收缓冲的输出使能，
此前硬接 +3V3、接收常开。**已采纳。**

**改动**

| | |
|---|---|
| 断开 | `U3.7 (2OE)` 与 `+3V3` 的直连 |
| 新增 | **R7 = 10 kΩ 0603**（`C25804`，与 R1/R2/R4/R5 同一颗料，不新增料号） |
| 新网络 | **`RX_EN` = `U1.1 (PB7/PB8)` · `U3.7 (2OE)` · `R7.1`** |
| 保留 | `R7.2 → +3V3`（上拉） |

**为什么选 U1.1**：U1 空闲的是 1 脚 (PB7/PB8)、3 脚 (PC15)、20 脚 (PB3/PB4/PB5/PB6)。
3 脚是 PC15，在 G0 上与 LSE 共用、驱动能力受限；20 脚并了四个口最灵活，留着。
1 脚是普通 GPIO，且与 `DE`/`MCU_TX`/`MCU_RX` 同在下排，走同一条通道。

**默认行为完全不变** —— MCU 复位期间 PB7 高阻，R7 把 `2OE` 拉高，接收缓冲照常开着。
固件一行不写，跟改动前一模一样。这是**预留**：想消掉发送期间的回显时，把 PB7 配成推挽
输出拉低即可，同时打开 `MCU_RX` 脚的内部上拉，避免 `2Y` 高阻时 RX 浮空 ——
这正是此前否掉「`2OE` 接 DE」方案的那个顾虑，用独立 GPIO + 内部上拉就解决了。

**改后复查**：元件 26→27、网络 23→24，`RX_EN` = 3 个脚，`+3V3` 里 `U3.7` 已移出、
`R7.2` 顶上。立创 DRC **0 违规**，异网最小间距 **0.160 mm**（改前 0.153），
其余各项与 2026-09-07 首次复查一致。

**顺带更正**：本目录 `imu_to_dxl-接线表.md` 的「悬空脚」清单此前误列了 2、16、17 脚
（它们分别接 `OSC_IN`、`UART_TX`、`UART_RX`），已改。现在真正空闲的只有 3 脚与 20 脚。

### 2026-09-07 · 关于 U3 缓冲器的三个疑问（两条不采纳，一条改画法）

评审人查了 SN74LVC2G241 手册，对 U3 的接法提了三点。逐条核过 —— 网表是从
PCB 里现读的（PCB 网络由原理图导出，等价于原理图连接）：

```
U3 脚1  1OE#  → DE          脚5  2A   → DXL_DATA
U3 脚2  1A    → MCU_TX      脚6  1Y   → DXL_DATA
U3 脚3  2Y    → MCU_RX      脚7  2OE  → 3.3V
U3 脚4  GND   → GND         脚8  VCC  → 3.3V

DXL_DATA  4 脚：R5.2 R6.1 U3.5 U3.6     ← 不含 U3.7
DE        3 脚：R4.2 U1.8 U3.1
MCU_TX    2 脚：U1.9 U3.2
MCU_RX    2 脚：U1.10 U3.3
```

**① 「A 是输入、Y 是输出，所以脚3 该接 DXL_DATA、脚5 该接 MCU_RX」—— 前提对，结论反了**

手册原文没错：器件是两路独立使能的 1 位线路驱动器，数据方向恒为 **A → Y**。
但据此换线就错了：

- `MCU_RX` 是**要被缓冲器驱动的**网络（送进 MCU 的接收脚），必须落在**输出脚 Y**
  → 现在在脚3（2Y）✅
- `DXL_DATA` 是**要被读进来的**网络（总线上舵机发的），必须落在**输入脚 A**
  → 现在在脚5（2A）✅

按建议对调后，通道2 变成 `MCU_RX(2A) → DXL_DATA(2Y)`，等于从 MCU 的接收脚
往总线上发数据 —— RX 是输入脚不输出电平；而且 `1Y` 与 `2Y` 会同时驱动
`DXL_DATA`，两个驱动器直接对打。

现在的分工是标准半双工接法：**通道1 = 发**（`MCU_TX → 总线`，受 DE 控制），
**通道2 = 收**（`总线 → MCU_RX`，常开）。**不采纳。**

**② 「2OE 该串个上拉电阻，否则上拉太强」—— 电气上不成立，但画法要改**

`2OE` 是 CMOS 逻辑输入，输入电流量级 ±1 µA，直接接 VCC 是手册的标准用法。
串电阻没有任何收益，反而给高阻输入引入干扰耦合。

「上拉太强」这个担心，只有当该节点是**数据线**时才成立 —— 它不是：
`DXL_DATA` 网络只有 4 个脚（`R5.2` `R6.1` `U3.5` `U3.6`），**不含 `U3.7`**。
总线上拉是 `R5 = 10 kΩ`，值也合适。

**但这条提醒有价值**：会产生这个误解，是因为图上「2OE 的 3.3V 符号」正好压在
`DXL_DATA` 节点正上方，视觉上像连成一片。**已列为待改项：把该 3.3V 符号移开、
走线绕行**，消除歧义。属画法问题，不改电气连接。

**③ 「要默认导通的话，1OE# 应该接低电平」—— 默认不导通是有意的，不采纳**

`1OE#` 低有效，`R4` 把它**上拉到高**，意味着通道1（`MCU_TX → 总线`）
**默认关闭**。这是刻意的：

- 上电到固件跑起来之前，以及 MCU 死机 / 复位期间，本板**绝不能驱动总线**。
  总线是 15 个舵机共用的，一旦被钉住，整条链路通信全废。
- 若把 `1OE#` 常接低，`MCU_TX` 会一直往总线上灌，空闲高电平把总线拉死，
  舵机永远回不了包 —— 半双工不成立。

发送时由 MCU 把 `DE` 拉**低**。STM32 的 USART 硬件 Driver Enable 支持该极性，
`CR3.DEP = 1` 一个位搞定，外面不用加反相器。

> 这条与 2026-09-06 第 ① 条（社区反馈要求 DE 上拉）方向一致 ——
> 那次加 R4 正是为了保证「默认不驱动总线」，此处不能反过来。

**待办**：原理图上把 `U3.7` 的 3.3V 符号挪开，避免与 `DXL_DATA` 节点视觉相连。

### 2026-09-06 · 社区反馈（三条，两条已改）

**① DE 脚要上拉 —— 已改，这是漏项**

`U3.1 (1OE#)` 是低电平使能发送。上电与复位期间 MCU 的 **PA1 是高阻**，此脚浮空；
**若浮成低电平，发送缓冲就打开，本板会往总线上灌数据、与 15 个舵机全部撞车。**

已加 **R4 10 kΩ，DE → 3.3 V**。

此前在 `SPI_CS` 上加 R1 上拉正是同一个道理，**但没有推广到 DE**，属实是疏漏。

**② 两个 `DXL_DATA` 要连一起并上拉 —— 已改**

电气上原本就是同一个网络（`U3.5 2A` / `U3.6 1Y` / `J1.3` / `J2.3`），
但图上画成了两根各自带标签的短线，**看起来像没连**，是画法不够直观。已改为显式连接节点。

上拉这条也对：总线空闲无人驱动时，`2A` 这个 CMOS 输入浮空会有穿透电流，
UART 也可能把噪声当起始位 —— 本板应当自己定义空闲电平，不该依赖主机。
已加 **R5 10 kΩ，DXL_DATA → 3.3 V**。

**③ 只留一个 3P 连接器 —— 未采纳，理由见上面第 3 条**

该建议在本板确定为叶子节点时成立；但若本板是链条第一个节点则必须两个座子，
而官方拓扑无从确认。保留两个，靠铜皮宽度解决过流。

改完复核：`DE` 由 2 脚变 3 脚，`DXL_DATA` 由 4 脚变 5 脚，
全图无悬空脚、无短路、无重名网络。

### 2026-09-06 · 对照官方 HAT 复审（补两处保护）

把 [`pollen-robotics/elec_RPI_Robot_HAT`](https://github.com/pollen-robotics/elec_RPI_Robot_HAT)
的 `dynamixel.kicad_sch` 逐器件读了一遍，和本板对比。

**HAT 的 TTL 半双工电路**

```
                        ┌── R31 10k ── +3V3
   IO_15 (RX) ◄── U6 ───┘                    ┌── R32 10k ── +3V3
              (1G125, OE# 低有效)             │
                        ▲                     ▼
   IO_14 (TX) ──┬── U7 ──────────────────────► ● ── R33 150R ──┬── TH1 100R ── J13.3 / J14.3
                │  (1G126, OE 高有效)                       D4 5V1
                └── R27 10k ── Q1 (PNP) ── Dynamixel_dir        ⏚
```

**逐项对比**

| | 官方 HAT | 本板 | |
|---|---|---|---|
| 收发缓冲 | 1G125 + 1G126 两颗 | SN74LVC2G241 一颗 | 同逻辑 |
| 方向控制 | 从 TX 自动派生（Q1 + RC） | **USART2 硬件 DE** | 本板更好，见下 |
| 总线上拉 | R32 10 kΩ | R5 10 kΩ | 一致 |
| **数据线串阻** | R33 150 Ω + TH1 100 Ω | ❌ 无 → **已补 R6 150 Ω** | |
| **数据线钳位** | D4 5V1 | ❌ 无 → **已补 D2 5V1（同料号 `C151348`）** | |
| 电源保护 | 无（`+BATT` 直通连接器） | F1 PPTC + D1 TVS | 本板更好 |

**方向控制为什么本板更好**：HAT 从 TX 派生方向，靠 RC 时序回到接收态，
**释放早了会截断最后一个停止位**——这是 TX 派生方案的通病。
本板用 `USART2` 的硬件 DE，`DEAT`/`DEDT` 可按 1/16 比特精调，不存在这个问题。

**补完之后的数据线拓扑**（与 HAT 同构）：

```
U3.6 (1Y) ──┬─ DXL_DATA ─┬── R5 10k → 3.3V
U3.5 (2A) ──┘            │
                         └── R6 150Ω ──┬── DXL_BUS ── J1.3 / J2.3
                                       │
                                    D2 5V1
                                       ⏚
```

上拉留在**缓冲侧**（R5 在 R6 之前），与 HAT 的 R32 位置一致 ——
这样即使不插总线，`2A` 这个 CMOS 输入也有确定电平。

本板只串 150 Ω（HAT 是 250 Ω），因为 HAT 侧已经有 250 Ω，
总线上串太多会拖慢边沿。

复核：`DXL_DATA`（缓冲侧）4 脚、`DXL_BUS`（连接器侧）4 脚，
全图无悬空脚、无短路、无重名网络。

**顺带纠正本文档此前一处错误**：HAT 的 `TH1 100R 热敏`串在**数据线**上，
不是电源线上。`+BATT` 到 J13/J14 的第 2 脚是**粗线直通、无限流**。

### 2026-09-06 · 阻容封装统一改 0603

所有 0402 阻容改为 **0603**，D2 从 SOD-323 改为 **SOD-123**。

理由不是「0402 手焊不了」—— 板上有 **LGA-14 的 LSM6DSV16X**（底部焊盘 3 × 2.5 mm），
本来就必须上热风或回流，有那套工具 0402 也不难。

**真正的理由是调试期返修**：串阻要从 150 Ω 试到 33 Ω、某个上拉要摘掉、
去耦要补一颗 —— 这些在 0603 上拿烙铁几秒就能做，0402 得重新架热风。
一块没打样验证过的板子，第一版必然要改几次。

代价很小：11 个器件多占约 16 mm²，不到 45 × 22 mm 板面积的 2%。
而且 0603 这几个值**全在立创基础库**（10 kΩ `C25804` · 150 Ω `C22808` ·
33 Ω `C23140` · 100 nF `C14663`），比原来 0402 的扩展库还省上料费。

> C6（10 µF/25 V）保持 0805；C5（4.7 µF）、C7（10 µF）本来就是 0603。

换封装时同坐标同角度重放，实测**引脚坐标不变、连线一根没断**。
一个坑：`SOD-123` 的符号引脚顺序与 `SOD-323` 相反，换完 **D2 极性翻了**
（阴极跑到接地侧，正常工作会把总线钳到 0.7 V），已按引脚名核对并改正。
`create()` 的 `rotation` 参数在这个 API 里符号相反 —— 传 90 存进去是 270。

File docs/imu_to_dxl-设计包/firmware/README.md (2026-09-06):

# firmware/ — `imu_to_dxl` 固件

> **协议层已完成并通过主机测试**（纯 C99，无硬件依赖）；
> STM32 外设层（I2C/UART 初始化）与 IMU 寄存器序列为骨架，标注了 TODO/待核对。

## 文件

| 文件 | 状态 | 说明 |
|---|---|---|
| `src/crc16.c/.h` | ✅ 完成并测试 | Dynamixel V2 CRC-16，与 dynamixel_sdk 位级一致 |
| `src/dxl_slave.c/.h` | ✅ 完成并测试 | 从机状态机：PING / READ / SYNC_READ；CRC 错与非本板帧正确沉默 |
| `test/test_protocol.c` | ✅ 6/6 通过 | 主机可跑：`cc -Wall -Isrc src/crc16.c src/dxl_slave.c test/test_protocol.c -o t && ./t` |
| `src/imu_lsm6dsv16x.c/.h` | 🔶 骨架 | I2C 读 + fp16 编码已写；SFLP/CTRL 初始化序列待对照数据手册填 |
| `src/main.c` | 🔶 骨架 | 主循环结构完整；HAL 外设初始化留 TODO |

## 行为对齐（全部有源码出处，见 ../设计规格.md 第二节）

- ID 200 / 1Mbps 8N1 / 读 124 取 12 字节 / 主机超时 30ms
- 陀螺 i16 LE（±500 dps 原始计数）、四元数 fp16 LE（w 主机自算）
- 状态包 23 字节（12 数据时），CRC 覆盖 ID..PARAMS

## 上板步骤（打样回来后）

1. STM32CubeIDE 建 G031 工程（或 platformio `ststm32`），把 `src/` 拷进工程
2. 补 `main.c` 的 HAL 初始化 TODO（I2C1 400k、USART1 1M、RX 中断）
3. 照 datasheet 补 `lsm6dsv16x.c` 初始化 TODO（重点：陀螺 FS ±500 dps 别配错）
4. SWD 烧录 → USB-TTL 单板自测 PING → 上总线联调（验收清单见规格文档第七节）

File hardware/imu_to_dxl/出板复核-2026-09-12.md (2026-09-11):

# imu_to_dxl 出板复核（2026-09-12）

当前设计可作为台架首版打样的基础，但现有证据不足以直接判定“电气全部验证通过，可以按装机终版下单”。应先确定接线拓扑和连接器、纠正调试接线文档，并从最终工程重新执行规则检查和导出生产文件。少量台架打样通过后再决定装机版本。

本次只新增复核记录，没有修改工程、PCB、原理图或原有文档。

## 复核对象与验证边界

- 实际读取本目录 README、接线表、原理图 PDF、PCB PDF 和设计包固件；只读检查 `.eprj2` 数据库结构，并查看 STEP 的装配对象名称。
- 两份 PDF 内创建日期均为 2026-09-08。PCB PDF 共 7 页，第 5 页含顶层走线与丝印，第 6 页含底层走线与铺铜；不能因为第 2 页为空就认定没有铜层。
- PCB PDF 的 BOM 为 29 个器件、20 项；J4/J5 为 JST `B3B-PH-K-S(LF)(SN)` / `C131339`，X1/R3/C9 均已列入。
- `.eprj2` 是 SQLite；`documents`、`coppers` 等表为空，设计内容存于编码的 `history_data`。本次未解码成完整机器网表，不能据此声称已完成原理图与 PCB 的逐网络等价验证。
- 本目录未发现 Gerber、钻孔生产文件、独立 BOM/贴片坐标文件或可重放的当前 ERC/DRC 报告。本次没有在嘉立创 EDA 中重跑 ERC/DRC。README 的“DRC 0 违规”、精确线距、走线数、网络数属于既有记录，不能改写成此次独立实测结果。
- 未做装配体干涉检查，未测量实际安装净空，未验证飞特线端实物，也未做通电、波形、温升或整机测试。

## 影响下单和使用方式的发现

### 1. J4/J5 不能沿用 JST EH 的 3 A 载流结论

README 的载流说明覆盖 `J1.2 → J2.2 → J5.2 → J4.2`，却只引用了 JST EH 的 3 A 额定值。

JST 官方 PH 规格为 **2 A（AWG 24）**；EH 为 **3 A（AWG 22）**。线规、接触件、温升等条件也需要匹配。只要下游舵机电流经过 J4/J5，就不能用 EH 的 3 A 或铜箔估算的 3.2 A 作为整条路径的能力。[JST PH](https://www.jst-mfg.com/product/pdf/eng/ePH.pdf)、[JST EH](https://www.jst-mfg.com/product/pdf/eng/eEH.pdf)

仓库自身又同时出现旧版“单舵机额定 500 mA”和新版“7.4 V 时额定 900 mA”的记录。**若采用后者，4 颗就是 3.6 A**，超过 PH 2 A，也超过 EH 3 A。这是依据仓库参数的条件计算，本次没有取得飞特原始确认书重新核实该电流。

原理图确认 F1 只串在本板 LDO 取电支路，**不会保护连接器之间的舵机直通电流**。

处理：首版建议作为末端节点，只给自身取电，不经本板给下游舵机供电。若必须做舵机供电中继，应按实际舵机型号、线束、持续与峰值电流重做连接器和铜箔核算；加宽铜箔不能解决连接器额定值不足。

### 2. “PH 本体约 6 mm，所以能放入 6.65 mm 内腔”不能成立

JST PH 官方目录给出的立式连接器**插合安装高度为 8 mm**，EH 为 8.1 mm。机械检查必须包括插好的线端、出线弯曲空间、PCB 厚度、焊脚和安装结构，而不能只看空板座子的塑料体高度。[JST PH 目录第 1 页](https://www.jst-mfg.com/product/pdf/eng/ePH.pdf)、[JST EH 目录](https://www.jst-mfg.com/product/pdf/eng/eEH.pdf)

如果板面到障碍物的真实净空只有 6.65 mm，PH 立式插合体也放不下。**6.65 mm 在本次仍是未验证的条件，不是已测得的整机尺寸。**逆向文档还说明原锁扣位于壳体背面，且锁扣是否用于固定本板仍属推断，所以必须先确定本板的实际安装位置。

另一个未关闭的问题是 PH 与飞特 `AMP2.0-3P` 的实际配合。相同 2.0 mm 间距不能保证壳体、锁扣、端子方向、孔径和本体让位兼容，不能承诺“以后换系列无需改焊盘和布线”。下单装机版前应拿实际线束试插、量尺寸并核对通断与极性。

### 3. J3 文档存在电源脚错误，不能直接沿用旧四针排线

原理图 PDF 中 J3 为：

| 脚号 | 实际网络 | MCU 侧 |
|---|---|---|
| 1 | GND | 地 |
| 2 | SWDCLK | U1.19 |
| 3 | SWDIO | U1.18 |
| 4 | UART_RX | U1.17，重映射 PA10 / USART1_RX |
| 5 | UART_TX | U1.16，重映射 PA9 / USART1_TX |
| 6 | 3.3V | 板上 3.3 V 电源 |

接线表不仅把 UART_TX/RX 写反，`+3V3` 网络一节还把 **J3.4** 列成电源脚；实际为 **J3.6**。因此“旧四针 SWD 排线直接插 1–4 仍可用”的承诺应删除，按具体调试器的引脚定义重新配线。需要 VTref 的调试器应感知实际 3.3 V 电源，不能把 J3.4 当作 VTref。USB-TTL 的 TX 接 J3.4，RX 接 J3.5，并共地。

这些是可明确确认的文档错误。最终制板前还应以 EDA 导出的机器网表确认 PCB 与该原理图一致。

### 4. 丝印与生产导出仍需收尾

PCB PDF 第 5 页可见 U2/C7 位号重叠；建议移开，并统一检查器件一脚、二极管阴极与连接器极性标记。D1 位号旋转本身不是电气错误，重点是可读性与阴极标记是否明确。

修订后应在同一份最终工程中完成原理图/PCB 同步、器件属性核对、重新铺铜、ERC/DRC 和未布线检查，再导出 Gerber、PTH/NPTH 钻孔、BOM、贴片坐标；重开生产文件核对板框、孔、阻焊、钢网和器件方向。

网络数 23/24、34 mm/40 mm 孔距、晶振默认不贴/实贴、接收使能硬接电源/经 R7 控制等历史描述混杂，应同步整理。网络总数不能只按文字把 23 改成 24，应以最终导出的机器网表为准。

## 核心电路与参考评审的核对结果

| 项目 | 此次结果 |
|---|---|
| 电源链 | 原理图可见 VDD_BUS 经 F1 到 VDD_F，D1 阴极及 C6/C8 接 VDD_F，HT7533-1 输出 3.3 V；管脚 1=GND、2=VIN、3=VOUT 与合泰手册一致。未做瞬态及温升验证。 |
| U3 收发方向 | U3.2 输入 MCU_TX、U3.6 输出 DXL_DATA；U3.5 输入 DXL_DATA、U3.3 输出 MCU_RX，符合 TI A→Y 定义。1OE# 经 R4 上拉，2OE 经 R7 上拉并受 RX_EN 控制。 |
| U3 电平 | TI 规格支持输入及三态输出端最高 5.5 V 的工作条件。该能力不等于使能输出时可以承受另一设备任意驱动，仍需正确处理半双工方向和总线争用。 |
| U2 IMU | 原理图上的 SPI、供电、去耦及 Mode 1 的辅助引脚处理未发现明显接法错误；这不替代 LGA 焊盘映射、机器网表及焊接验证。 |
| BOOT0 | STM32G031F8P6 的 TSSOP20 第 19 脚为 PA14/BOOT0 复用，第 1 脚为 PB7/PB8。因此 RX_EN 在第 1 脚上拉不会直接把 BOOT0 拉高。 |
| BOOT 启动解释 | 参考中的“SWCLK 内部下拉，所以必然正常启动”不完整。启动还受 nBOOT_SEL/nBOOT0 等选项字节和 Flash 空片状态影响；ST 明确 nBOOT_SEL=1 时忽略 BOOT0 引脚。首烧后需读回选项字节并验证断电启动。 |
| D2 | 工程 BOM 为 BZT52C5V1-7-F / C151588 / SOD-123，厂商型号本来就是 SOD-123；“通常对应 SOD-323”这一前提有误。原理图阴极接 DXL_BUS，方向合理。5.1 V 是标称稳压值，不是所有浪涌下的最大钳位保证。 |
| X1 | 实际下载并读取 SCTF2020HQ344、2022-08-10、B01 承认书：S3D16.000000B20F30T 为 16 MHz、3.3 V ±10%，1=EN、2=GND、3=OUT、4=VDD，与原理图接法一致。 |
| 连接器脚序 | 原理图确认 J1/J2=GND/VDD_BUS/DXL_BUS，J4/J5=DXL_BUS/VDD_BUS/GND。飞特实际线端方向和配套型号仍需实物或完整厂家图纸确认。 |

电气核对来源：[TI SN74LVC2G241](https://www.ti.com/lit/ds/symlink/sn74lvc2g241.pdf)、[ST STM32G031](https://www.st.com/resource/en/datasheet/stm32g031c6.pdf)、[ST LSM6DSV16X](https://www.st.com/resource/en/datasheet/lsm6dsv16x.pdf)、[Holtek HT75xx-1](https://www.holtek.com/webapi/116711/HT75xx-1v281.pdf)、[ST 启动配置培训资料](https://www.st.com/resource/en/product_training/STM32G0-Memory-Flash-FLASH.pdf)、[Diodes BZT52C5V1](https://www.diodes.com/part/view/BZT52C5V1/)、[LCSC C151588](https://www.lcsc.com/product-detail/C151588.html)、[SCTF 原厂承认书的公开副本](https://file.elecfans.com/web2/M00/64/77/poYBAGMHNxWAdZcVABEzOp1MOQk264.pdf)。

## 固件尚未适配当前 PCB

`docs/imu_to_dxl-设计包/firmware/src/main.c` 仍为 I2C1 / USART1 初始化骨架，`bus_send()` 为空实现；`imu_lsm6dsv16x.c` 仍调用 I²C 钩子，SFLP 初始化保留 TODO。当前原理图则使用 **SPI1 + USART2 + PA1 低有效 DE**，调试串口才是重映射后的 USART1。

这不阻止裸板台架打样，但它意味着没有一份已适配、可直接烧录并证明整板工作的交付固件。首次调试应完成 SWD 连接、3.3 V 与时钟、SPI WHO_AM_I、SFLP 输出、USART2 收发和回显处理，再用实际总线验证 1 Mbps 通信。

## 建议的放行条件

| 交付目标 | 放行条件 |
|---|---|
| 少量台架样板 | 明确不经本板给舵机供电；纠正接线文档和丝印；冻结最终工程并重跑规则检查，复核生产文件后再下单。连接器机械装配可在台架阶段继续验证。 |
| 可直接装机的 PCBA | 在上述条件外，完成实际线束配合、插合净空、安装孔/支架、方向确认；如有下游负载，再完成载流核算与实测。 |
| 批量或长期使用 | 首样完成通电、冷启动、IMU 数据、1 Mbps 总线、温升和电机动作干扰测试后再决定。 |

本次检查的文件 SHA-256：

```text
imu_to_dxl.eprj2       4fef83c09d2db93c257a41728f3a30559384a1a201ccc825cb206e3c4bb9a243
imu_to_dxl-原理图.pdf   ef141102139d60c96cb195b587af0e014aad1341010ed05e4d3acf0d12787e82
imu_to_dxl-PCB.pdf     e5a3c349bcacbf8c6c7c4d9f524aa899472b13c2fc159d00d797a3efffadc001
```

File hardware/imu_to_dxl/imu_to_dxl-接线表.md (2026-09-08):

# imu_to_dxl 接线表

> 手工连线用。器件位号与 `microduck-replica/BOM.md` 一致。
> 状态：方案稿，未经实物验证。

## 器件清单（含立创编号）

| 位号 | 器件 | 封装 | 立创编号 |
|---|---|---|---|
| U1 | STM32G031F8P6 | TSSOP-20 | C529334 |
| U2 | LSM6DSV16XTR | LGA-14 | C5267406 |
| U3 | SN74LVC2G241DCUR | VSSOP-8 | C10430 |
| U4 | HT7533-1（30V 输入，100mA） | SOT-89 | C14289 |
| F1 | PPTC MF-NSMF020X-2（24V / 200mA 保持） | 1206 | C210358 |
| D1 | TVS SMF12A | SOD-123FL | C2943870 |
| R1, R2, R4, R5 | 10kΩ | **0603** | C25804 |
| R6 | 150Ω | **0603** | C22808 |
| D2 | BZT52C5V1 5.1V 稳压管 | **SOD-123** | C151588 |
| C1–C4, C8 | 100nF 50V | **0603** | C14663 |
| C5 | 4.7µF / 16V X5R | 0603 | C19666 |
| C6 | 10µF / 25V X5R | 0805 | C15850 |
| C7 | 10µF / 10V | 0603 | C19702 |
| J1, J2 | B3B-EH-A（3P **2.5mm**，Dynamixel / 官方 HAT 线） | 直插 | C160259 |
| **J4, J5** | **B3B-PH-K-S（3P 2.0mm 立式，对口飞特 `AMP2.0-3P`）** | 直插 | 待定 |
| J3 | SWD+串口 6P 排针 PZ254V-11-06P | 直插 | C492405 |

## 网络表（23 个网络）

### VDD_BUS —— 舵机总线原压（2S 锂电 6.0–8.4V）
J1.2 · J2.2 · **J4.2** · **J5.2** · F1.1

> 四个座子的 `VDD_BUS` 走**直通铜皮**：`J1.2 → J2.2 → J5.2 → J4.2` 全程 0.76 mm。

### VDD_F —— 保险丝之后
F1.2 · D1 阴极 · C6.1 · C8.1 · U4.2 (Vin)

### +3V3
U4.3 (Vout) · C7.1 · U1.4 (VDD/VDDA) · C4.1 · C5.1 · R2.2 ·
U2.5 (Vdd_IO) · U2.8 (Vdd) · C1.1 · C2.1 · R1.2 ·
U3.8 (VCC) · C3.1 · J3.4 · **R7.2**

### GND
D1 阳极 · C6.2 · C8.2 · U4.1 (GND) · C7.2 ·
U1.5 (VSS/VSSA) · C4.2 · C5.2 ·
U2.2 (SDx) · U2.3 (SCx) · U2.6 (GND) · U2.7 (GND) · C1.2 · C2.2 ·
U3.4 (GND) · C3.2 · J1.1 · J2.1 · J3.1 · **J4.3** · **J5.3** · C9.2 · X1.2

### 复位
| 网络 | 连接点 |
|---|---|
| NRST | U1.6 (PF2-NRST) · R2.1 |

R2 另一端 (R2.2) 接 +3V3，构成 10k 上拉。

### 四个上拉电阻（R1/R2/R4/R5，另一端全部接 +3V3）

| 位号 | 拉住谁 | 为什么 |
|---|---|---|
| **R1** | `SPI_CS` | 上电与复位期间 PA4 高阻，CS 浮着可能被 IMU 误判成 I²C 模式，或把总线噪声当命令。**必须** |
| **R2** | `NRST` | 芯片内部已有 ~40 kΩ 弱上拉，外加 10 kΩ 提高抗干扰。加强项 |
| **R4** | `DE` | `1OE#` **低电平使能发送**。复位期间 PA1 高阻，此脚若浮成低电平，发送缓冲打开，本板会往总线上灌数据、与 15 个舵机撞车。**必须** |
| **R5** | `DXL_DATA` | 总线空闲无人驱动时，`2A` 这个 CMOS 输入浮空会有穿透电流，UART 也可能把噪声当起始位。本板自己定义空闲电平，不依赖主机 |

> R4 与 R5 是 2026-09-06 按社区评审意见补的。此前只在 CS 上做了上拉，
> **同样的道理没有推广到 DE，这是漏项**。

### IMU（SPI 四线 + 两路中断）
| 网络 | U1 (STM32) | U2 (LSM6DSV16X) | 其他 |
|---|---|---|---|
| SPI_CS | 11 · PA4 | 12 · CS | R1.1（R1.2 接 +3V3 上拉） |
| SPI_SCK  | 12 · PA5 | 13 · SCL | |
| SPI_MISO | 13 · PA6 | 1 · SDO/SA0 | |
| SPI_MOSI | 14 · PA7 | 14 · SDA | |
| IMU_INT1 | 7 · PA0  | 4 · INT1 | |
| IMU_INT2 | 15 · PB0/PA8 | 9 · INT2  | |

### 半双工总线（U3 = SN74LVC2G241 双缓冲）
| 网络 | 连接点 |
|---|---|
| MCU_TX | U1.9 (PA2 · USART2_TX) · U3.2 (1A) |
| MCU_RX | U1.10 (PA3 · USART2_RX) · U3.3 (2Y) |
| DE | U1.8 (PA1 · USART2_DE) · U3.1 (1OE#) · **R4.1** |
| DXL_DATA | U3.6 (1Y) · U3.5 (2A) · **R5.1** · **R6.1** —— 缓冲侧 |
| **DXL_BUS** | **R6.2** · **D2 阴极** · J1.3 · J2.3 · **J4.1** · **J5.1** —— 连接器侧 |
| **RX_EN** | **U1.1 (PB7/PB8)** · **U3.7 (2OE)** · **R7.1** —— 接收缓冲使能，2026-09-07 补 |

`U3.7 (2OE)` 原为直接接 +3V3，2026-09-07 改成 **`RX_EN` 网络**：经 **R7 10 kΩ 上拉到
+3V3**，同时引一根线到 **U1.1 (PB7/PB8)**。

**默认行为不变** —— MCU 复位期间 PB7 是高阻，R7 把 `2OE` 拉高，接收缓冲照常开着，
固件一行不写也跟改动前完全一样。这是**预留**：想关掉发送期间的回显时，把 PB7 配成
推挽输出拉低即可，同时打开 `MCU_RX` 脚的内部上拉，避免 `2Y` 高阻时 RX 浮空。

### 调试口 J3（6P，`PZ254V-11-06P` / `C492405`）

| 脚 | 网络 | 来源 |
|---|---|---|
| 1 | GND | |
| 2 | SWDCLK | U1.19 (PA14) |
| 3 | SWDIO | U1.18 (PA13) |
| 4 | **UART_TX** | **U1.16** `PA11[PA9]` → 重映射为 **PA9** = `USART1_TX` |
| 5 | **UART_RX** | **U1.17** `PA12[PA10]` → 重映射为 **PA10** = `USART1_RX` |
| 6 | +3V3 | |

前 4 脚顺序不变，**原来的 4 针 SWD 排线插 1–4 仍可用**。

脚 16/17 的重映射靠 `SYSCFG_CFGR1`（DS12992 Rev 3, Table 12 脚注 4）。

**为什么不上 USB**：STM32G031 **没有 USB 外设**（手册全文搜 USB 零命中，Development support
只写 "serial wire debug (SWD)"）。加 USB 要额外一颗 CH340/CP2102，45×22 mm 板上不划算。
调试用 SWD 就够：

| 方式 | 需要什么 | 说明 |
|---|---|---|
| **RTT**（推荐） | 只用 J3 的 1–4 脚 | `probe-rs` 支持 CMSIS-DAP 跑 RTT，直接读目标 RAM，**不停 CPU**，对 50 Hz 控制环无影响 |
| 串口 printf | J3 的 4/5 脚 + 任意 USB-TTL | 走 USART1 |
| 半主机 semihosting | 只用 J3 | 每次 printf 停 CPU，控制环会崩，**别用** |
| ~~SWO / ITM~~ | — | **Cortex-M0+ 没有**，M3 以上才有 |

### 舵机接口 —— 两套并存，⚠️ **脚序是相反的**

板上有四个舵机总线座子，两两一组，三根线一一并联（同一个电气节点），
**但两组的引脚顺序完全相反** —— 因为两家的线序本来就不同。

**`J1` / `J2` —— `B3B-EH-A`，2.5 mm，配 Dynamixel / 官方 HAT 线束**

| 脚 | 网络 |
|---|---|
| 1 | GND |
| 2 | VDD_BUS |
| 3 | **DXL_BUS** |

**`J4` / `J5` —— `B3B-PH-K-S`，2.0 mm，配飞特 HD-1910 线束**

| 脚 | 网络 |
|---|---|
| 1 | **DXL_BUS** |
| 2 | VDD_BUS |
| 3 | **GND** |

> ⚠️ **千万别照着 `J1` 复制网络给 `J4`。** 飞特《HD-1910-C001 串型规格书》A/0
> 第 3/7 页 6-7 项写明线端是 `1=Signal / 2=Vcc / 3=GND`，与 Dynamixel 侧头尾颠倒。
> 好在 **2.0 mm 与 2.5 mm 插不进对方**，物理上杜绝了插错，只剩「画错」这一种可能。
> 四个座子的脚序已于 2026-09-08 从 PCB 网表反读复核，全部落对。
>
> 另注意 **`AMP2.0` 是 2.0 mm、`JST EH` 是 2.5 mm**，飞特线插不进 `J1`/`J2`，
> 反之亦然 —— 用哪套舵机就插哪一组。

> 📌 **脚 3 此前本表误记为 `DXL_DATA`**。2026-09-06 补入 `R6` 150 Ω 串阻后，
> 缓冲侧（`DXL_DATA`）与连接器侧（`DXL_BUS`）已是两个网络，连接器上是 `DXL_BUS`。
> 2026-09-08 更正。

## 悬空脚

- U1：**3 (PC15-OSC32_OUT)、20 (PB3/PB4/PB5/PB6)**
  - 3 脚已引到焊盘，与 2 脚一起构成有源晶振预留位（默认不贴），见下方「时钟」
  - 20 脚是唯一完全空闲的 GPIO（并了 PB3/PB4/PB5/PB6 四个口，最灵活），留作后用
  - 1 脚 (PB7/PB8) 原本空闲，2026-09-07 起用作 `RX_EN`
  - 2 脚 (PC14-OSC32_IN) 接 `OSC_IN`、16/17 脚 (PA9/PA10) 接 `UART_TX`/`UART_RX`
    —— 此前本表误列为悬空，2026-09-07 更正
- U2：10 (OCS_Aux)、11 (SDO_Aux) —— 辅助 SPI 不用，ST DS13510 允许悬空；保守做法是 OCS_Aux 接 Vdd_IO

**U2.2 (SDx) 与 U2.3 (SCx) 必须接地**，不可悬空 —— ST DS13510 Rev 1, Table 1。

## 时钟：用内部 HSI16，晶振位预留不贴

**这个封装接不了无源晶振。** DS12992 Rev 3, Table 12 (p.36)：TSSOP20 的 2 脚
(`PC14-OSC32_IN`) 附加功能含 `OSC_IN`，但 3 脚 (`PC15-OSC32_OUT`) 只有 `OSC32_OUT`、
**没有 `OSC_OUT`**；`PF0`/`PF1` 在这个封装根本没引出来。无源晶振要两个脚才能起振。

| 方案 | 可行性 |
|---|---|
| 无源高速晶振 | ❌ 缺 `OSC_OUT` |
| 有源晶振走 HSE 旁路（灌进 2 脚，3 脚可作 `OSC_EN`） | ✅ |
| 32.768 kHz LSE 无源晶振 | ✅ 但不能给 PLL 供时钟，只能校准 HSI16 |

HSI16 精度（Table 41, p.64）：出厂 −0.75%/+0.5%，0–85 °C 温漂 ±1%，电压漂移 ±0.1%
→ 最坏约 **−1.85% / +1.55%**。1 Mbps UART 典型容差 ±3%，够用但余量不多。

**做法**：2、3 脚引到焊盘，留一个 3225 有源晶振位 + 去耦位，**默认不贴**。
实测通信有问题再贴 16 MHz 有源晶振。

## 使能极性说明

`1OE#` 低电平使能发送缓冲，`2OE` 接高电平使接收缓冲常开。

- PA1 是 USART2 的硬件 DE 脚，配置 `CR3.DEP = 1`（DE 低有效），收发切换由硬件完成
- 接收常开意味着发送时会在 RX 上收到自己的回显，固件按发送长度丢弃即可
- 备选方案是 `2OE` 也接 DE（发送时关掉接收缓冲），但那样发送期间 MCU 的 RX 脚悬空，重新使能时可能产生假起始位，不推荐
- **2026-09-07 改进**：`2OE` 不再硬接 +3V3，而是经 R7 10 kΩ 上拉、同时引到 `U1.1 (PB7/PB8)`。
  默认仍是常开（行为不变），但固件多了一个选项 —— 想关接收时拉低 PB7，并打开 MCU RX 脚的
  内部上拉解决浮空。比接 DE 更灵活：关不关、何时关，由固件自己定

## HD-1910-C001 实参（飞特官方产品页，预售期）

飞特为小鸭子专门做的一颗，页面标题即「**开源小鸭舵机** —— 串行总线舵机，专为小鸭子 AI 玩偶定制开发」。
舵机本体标注：**「三针接口 · TTL串行总线」**。

| 项 | 值 |
|---|---|
| 电压范围 | **5 V – 8.4 V** |
| 堵转扭力 | **10 kg·cm = 0.98 N·m** |
| 额定负载 | **3.0 kg·cm = 0.294 N·m** |
| 空载速度 | 0.09 s/60°（110 RPM） |
| **静态电流** | **21 mA** |
| **空载电流** | **140 mA** |
| **额定电流** | **500 mA** |
| **堵转电流** | **1.8 A** |
| 外观尺寸 | 34 × 20 × 23 mm |
| 重量 | 22.5 ± 2 g |
| 外壳 | PA + Fiber |

尺寸与 XL330（20×34×26 mm）同档，机械上近似可替换；扭矩比 XL330-M288（0.52 N·m）强近一倍。

> ⚠️ 别把 `HL-2915-C002` 规格书里的电气参数套到这颗上 —— 那是 12 V（9–14 V）机型。
> 可通用的只有连接器定义与协议部分。

### ⚠️ J1↔J2 直通路径的过流

J1 / J2 三根线一一并联，**本板若挂在链条中间，下游全部舵机电流都流经本板的连接器与铜箔**：

| 工况 | 单个 | ×15 |
|---|---|---|
| 静态 | 21 mA | 0.3 A |
| 空载转动 | 140 mA | 2.1 A |
| **额定负载** | **500 mA** | **7.5 A** |
| 堵转 | 1.8 A | 27 A |

而 **JST EH 额定电流仅 3 A**。

> F1（200 mA PPTC）**不受影响** —— 它只串在本板自取电那一路
> （`VDD_BUS → F1 → VDD_F → U4`），不在 J1→J2 直通路径上。

**二选一：**

1. **把本板挂在链条末端**（叶子节点），只用 J1，J2 空置或只接 1 个舵机 —— 流经本板的仅约 12 mA。**推荐**
2. 若必须置于链中，PCB 上 `VDD_BUS` 与 `GND` 从 J1 到 J2 走**大铜皮**（≥ 2 mm 或直接铺铜），
   并核算下游舵机数量不超过 3 A

## 飞特接口定义（官方规格书确认）

**来源**：飞特《HL-2915-C002 串型规格书》A/0，2026-02-27，第 4 页 6-7 项。

```
6-7  连接器和电缆 Connector and Cable
     类型 Type        AMP-3
     材质 Material    PP
     线长 Length      15CM / 25CM
     引脚定义         1  GND
     Pin Definition   2  Vcc
                      3  Signal/TTL
```

**`1=GND / 2=Vcc / 3=Signal`，与 Dynamixel 完全一致 → J1/J2 现有接法正确。**

关联证据：`HD-1910-C001.stp` 装配体里连接器零件名是 **`AMP-3P`**，且该装配体包含
`HL-2915-C002-20260409_ASM` —— 两款共用平台，接口定义通用。

### 同一份规格书里其它可用条目

| 项 | 值 | 意义 |
|---|---|---|
| 7-2 协议类型 | Half Duplex Asynchronous，**8bit / 1stop / No Parity** | 与本板一致 |
| 7-4 波特率 | 38400 ~ 1 Mbps，**出厂默认 1 Mbps** | 与 Dynamixel 同速 |
| 7-3 ID 范围 | 0–253，**出厂默认 ID 1** | 15 个舵机需逐个改 ID；本板用 200 不冲突 |
| 12 **信号高电平** | **2 V ~ 5 V** | 见下 |
| 12 信号低电平 | 0.0 V ~ 0.45 V | |
| 6-6 角度传感器 | 12 Bits 磁编码 | 磁编码 ⇒ **小端字节序** |

**信号电平两个方向都要看**：

1. 本板驱动总线 —— `SN74LVC2G241` 在 3.3 V 供电下输出约 3.3 V，落在舵机要求的 2–5 V 高电平窗口内 ✅
2. 舵机驱动总线 —— 它可能输出到 **5 V**；74LVC 在 3.3 V 供电时**输入耐 5.5 V** ✅
   （选 LVC 而非 LV/HC 正好卡住这条）

> ⚠️ 该规格书是 **HL-2915-C002（12 V，9–14 V）**，不是 HD-1910（5–8.4 V）。
> **电气参数不可混用** —— 供电范围、堵转电流、过压保护阈值都不同。
> 通用的只是**连接器定义与协议**部分。

### 背景：飞特不同系列的物理层不一样

官方各系列内存表手册（<http://doc.feetech.cn>，接口 `getQr/{q}`）原文：

| 系列 | 电平 | 默认波特率 |
|---|---|---|
| **STS**（磁编码） | **TTL 单总线** | **1M** |
| SCS（电位器） | TTL 单总线 | 1M / 500k |
| SMS（磁编码） | **RS485** | 115200 |
| HLS（磁编码） | 未注明 | 1M |
| SHC | CANopen | 125k |

「飞特 = TTL 单线」**只对 STS/SCS/HL 这一支成立**，SMS 是 RS485。换系列前先查它的手册。

## 协议自动识别（不用跳线、不用拨码）

两家包头天然可分，判别点是**第 3、4 字节**：

| | 包头 | 后续 | 校验 |
|---|---|---|---|
| Dynamixel V2 | `FF FF` | **`FD 00`** | CRC-16（poly 0x8005） |
| 飞特 STS/SCS | `FF FF` | `ID` + `LENGTH` | `~(ID+LENGTH+INST+参数)` |

无歧义：飞特包第 3 字节是 ID（可以是 0xFD），但**第 4 字节 LENGTH 永远不会是 0**
（最小为 2 = 指令 + 校验和）。所以 `FF FF FD 00` 只可能是 V2。

```
状态：未知 / 已锁 V1 / 已锁 V2

未知时，收到 FF FF 开头的包：
    if 字节[2]==0xFD && 字节[3]==0x00:
        按 V2 拆，算 CRC-16 → 过了记一票 V2
    else:
        按 V1 拆，算 ~sum   → 过了记一票 V1
    连续 3 票一致 → 锁定

锁定后：只按锁定协议解析，回复也用同一种
兜底：连续 100 包全解析失败 → 解锁重新识别
```

以下均以**飞特官方《舵机SCS通信协议》原文**为准：

- 帧格式：**1 起始位 + 8 数据位 + 无校验 + 1 停止位**，共 10 位
- 字头：连续两个 `0xFF`
- ID 范围 **0～253**（`0x00`～`0xFD`），**广播 ID = 254（`0xFE`）**
- 数据长度 **Length = 参数个数 N + 2**，所以**最小为 2，永远不会是 0** ← 判别无歧义的依据
- 校验和 = `~(ID + Length + Instruction + Param1 + … + ParamN)`，超 255 取低字节
- 同步读 `0x82`、同步写 `0x83`、PING `0x01`、读 `0x02`、写 `0x03`
- ⚠️ **多字节参数的字节序按舵机类型分**：「电位器类型舵机为**大端**（高字节在前），磁编码类型舵机为**小端**（低字节在前）」

三个要点：

1. **必须锁定，不能逐包判** —— 总线有噪声，某包被干扰成 `FD 00` 的样子会导致来回横跳
2. **回复用同一协议** —— 不只解析要分支，组包也要
3. **兜底解锁** —— 换舵机品牌时不必重烧固件

从机 ID 两边都用 **200**，与 15 个舵机（通常编 1–15）不冲突。

> 飞特 STS 的 `Return Delay Time` 默认 0，且手册标注 "Not functional on STS" ——
> 寄存器不生效，回复延迟完全由固件决定。

## 封装口径：阻容一律 0603

所有阻容用 **0603**，D2 用 **SOD-123**，不用 0402/SOD-323。

理由不是手焊 —— 板上有 LGA-14 的 LSM6DSV16X，本来就得上热风。
**真正的理由是调试期返修**：串阻从 150 Ω 试到 33 Ω、摘掉某个上拉、补一颗去耦，
0603 拿烙铁几秒就能改。第一版没验证过的板子必然要改几次。

代价：11 个器件多占约 16 mm²，不到板面积 2%。而且 0603 这几个值全在立创**基础库**
（10 kΩ `C25804` · 150 Ω `C22808` · 33 Ω `C23140` · 100 nF `C14663`），比 0402 的扩展库还省上料费。

> C6（10 µF/25 V）保持 0805；C5（4.7 µF）、C7（10 µF）本来就是 0603。

## 数据线保护（照 HAT 的做法）

```
U3.6 (1Y) ──┬─ DXL_DATA ─┬── R5 10k → 3.3V
U3.5 (2A) ──┘            │
                         └── R6 150Ω ──┬── DXL_BUS ── J1.3 / J2.3
                                       │
                                    D2 5V1
                                       ⏚
```

| 器件 | 作用 |
|---|---|
| **R6 150 Ω** | 源端串阻。限制短路电流、软化边沿降 EMI。1 Mbps 下延迟约占比特时间 3% |
| **D2 5V1** | 钳位。阴极接 `DXL_BUS`、阳极接地 |

**上拉留在缓冲侧**（R5 在 R6 之前）：这样即使不插总线，`U3.5 (2A)` 这个 CMOS 输入
也有确定电平，不会浮空。与 HAT 的 `R32` 位置一致。

> 官方 HAT 用的是 `R33 150R + TH1 100R` 串联共 250 Ω，外加 `D4 5V1` 钳位
> （`dynamixel.kicad_sch`）。**D2 与 HAT 的 D4 同型号、不同封装** —— HAT 是 SOD-323（`C151348`），本板用 SOD-123（`C151588`）便于返修。
> 本板只用 150 Ω，因为 HAT 侧已有 250 Ω，总线上串太多会拖慢边沿。

## 三道过压防线

1. **F1** PPTC 200mA 保持 / 24V —— 限流，防短路
2. **D1** TVS SMF12A —— 钳位，防舵机反电动势尖峰
3. **U4** HT7533-1 耐压 30V —— 即使前两道失效，LDO 本身扛得住

## 布局要点

- 2 层板，45 × 22mm，贴片件全在正面
- 3 个连接器（J1/J2/J3）排在同一条边，插件
- 两个 M2 安装孔，间距 34mm（与原版 `banana_pcb_locker` 兼容）
- C1/C2 紧贴 U2 的 Vdd / Vdd_IO 脚，走线尽量短
- C4（100nF）与 C5（4.7µF）紧贴 U1 的 4 脚 —— ST DS12992 Fig.13 要求"尽可能贴近引脚，或放在 PCB 背面正对该脚"
- DXL_DATA 走线加粗，远离 SPI

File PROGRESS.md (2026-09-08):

# 项目进度

**项目**：Microduck 复刻
**开始**：2026-08-28
**最后更新**：2026-09-06（复刻总清单：打印清单/缺件/采购/成本汇总；补齐孔径测试片 STL）
**仓库**：https://github.com/fanhao375/microduck-replica （公开）

---

## 目标

复刻 Pollen Robotics 的 **Microduck**（25cm 双足机器鸭，$399，2026 圣诞开卖）。
官方软件开源；硬件**部分开源** —— **HAT 板有完整 KiCad 工程与生产文件**
（[`elec_RPI_Robot_HAT`](https://github.com/pollen-robotics/elec_RPI_Robot_HAT)，Apache-2.0），
但 `imu_to_dxl` 板、可编辑机械 CAD、整机 BOM 与装配文档均未公开。

> **勘误 2026-09-03**：此前记录为「硬件不开源、无 PCB 原理图」，**判断错误**。
> 原因是只检索了 `microduck` 主仓，漏掉了同组织下 `elec_` 前缀的硬件仓库。

本项目从官方公开的 **MJCF 仿真模型 + 47 个 STL** 反推出机械复刻所需的全部信息。

---

## 总体状态

| 环节 | 状态 | 说明 |
|---|---|---|
| 零件几何 | ✅ 完成 | 47 个 STL |
| 装配关系 | ✅ 完成 | 精确到 0.1mm，已出爆炸图 |
| CAD 装配体 | ✅ 完成 | 已应用世界变换，可直接导入 |
| 关节参数 | ✅ 完成 | 14 个受控关节的轴线与行程 |
| 质量惯量 | ✅ 完成 | 15 个刚体 |
| 紧固件清单 | ✅ 完成 | 孔特征反推，M2 系统 |
| 执行器选型 | ✅ 完成 | XL330 ×15，BAM M6 参数 |
| 轴承规格 | ✅ 完成 | Ø22×16×4、Ø15×10×3 |
| **电控方案** | ✅ 完成 | 从 Rust 源码完整还原，见「第 6 批」 |
| 主控选型 | ✅ 完成 | **Radxa Zero 3W 市售模块**，非定制载板 |
| **HAT 板** | ✅ 官方已开源 | KiCad + Gerber + BOM + 贴片坐标，直接打样（4 层板） |
| **`imu_to_dxl` 板** | ✅ 已自绘（未打样） | 全网无公开工程；芯片/地址/协议已完整还原，本仓库提供原理图 + PCB |
| **走线方案** | ❌ 缺失 | 官方无任何资料 |
| **控制软件** | ✅ 可用 | 主控同款则官方 Rust 运行时直接跑；换主控才需移植 |
| **策略重训** | ✅ 非必需 | 硬件同款则官方 9 个 ONNX 直接可用；改本体/电控才需重训 |

---

## 已完成

### 第 1 批 · 资料摸底

- ~~确认 **Microduck 硬件不开源**~~：`microduck` 仓库全是 Rust 软件，
  `docs/` 下 5 个子目录全是软件文档，全库搜不到任何 `.stl/.step/.f3d/bom` 文件
  —— **这条结论下错了**（2026-09-03 更正）。只查了主仓，没查同组织下 `elec_` 前缀的
  硬件仓库；**HAT 板在 [`elec_RPI_Robot_HAT`](https://github.com/pollen-robotics/elec_RPI_Robot_HAT)
  里是完整开源的**（Apache-2.0，含 KiCad + Gerber + BOM + 贴片坐标）。
  教训：判断「某项目有没有开源某部分」时，必须检索**整个组织**，不能只看主仓。
- 确认 **`microduck_rl` 里有 47 个 STL + 完整 MJCF**，这是唯一的几何来源
- 确认 **3D 模型许可证是 CC BY-NC-SA**（非商用），代码是 Apache-2.0
- 排除了 Open Duck Mini v2 路线（见「决策记录」）

### 第 2 批 · 装配图

- 用 MuJoCo 离屏渲染，白色天空盒，1600×2100
- 4 张常规视图 + 2 张爆炸图 + 1 张分色对照图
- 爆炸图沿运动学链逐级偏移（每级 48mm），越靠链末端炸得越远
- 自己实现了世界坐标→像素的投影，用于画标注引线与避让排版
- 产出：`assembly-drawings/`（7 张），脚本 `scripts/render_assembly.py`

### 第 3 批 · CAD 装配体

- 上游 47 个 STL 都是**零件自身坐标系**，直接导入 CAD 会全部堆在原点
- 从 MJCF 取每个 geom 的世界变换，应用后按刚体分组导出
- 产出：`cad/` —— 整机单文件（796792 三角面）+ 15 个部件，单位 mm
- 整机实测外形 **144 × 141 × 264 mm**（与官方标称 25cm 吻合）
- 脚本 `scripts/export_assembly_stl.py`

### 第 4 批 · 紧固件反推

- 写了孔特征识别：焊接顶点 → 建面片邻接图 → 按二面角 35° 切割光滑曲面片
  → 每片拟合圆柱（轴 = 法向协方差最小特征向量）→ 投影拟合圆求直径
  → 按法向朝向判别孔/凸台
- 47 个零件扫完耗时 2.5 秒
- 产出：`docs/紧固件反推.md`、`docs/hole_analysis.json`、`scripts/analyze_holes.py`

### 第 10 批 · 英文文档

- 背景：awesome 列表收录时特意标注 "In Chinese"；流量数据显示 Google 仅 5 次
  而 Bing 132 次，英文圈基本没进来
- 按访问量定优先级，先翻 `硬件方案逆向.md`（站内访问第 2，84 次），
  因为它是**全网独有内容** —— HF 员工 @mishig25 做的 3D 解剖页（3.6 万浏览）
  已覆盖「整机长什么样」那一层，规格类文档与其重合，而芯片地址、总线协议、
  12 字节数据块布局这些只有本仓库有
- 产出：`docs/hardware-teardown.en.md`（426 行）+ `docs/actuator-selection.en.md`（459 行），
  均与中文版互相链接
- 英文 README 的文档索引改为用 🇬🇧 标记哪些有英文版

### 第 9 批 · 执行器选型分析

- 回答两个高频问题：为什么用舵机不用闭环步进；能不能不改机械件换成便宜的 STS3215
- **硬数据对照**：同为 15 刚体双足鸭，XL330 版 **737.2 g** vs STS3215 版 **2107.1 g**，
  差 2.86 倍 —— Open Duck Mini v2 就是「STS3215 版的答案」（42cm / 2.1kg）
- **执行器参数对照**：kp 差 32×、forcerange 差 3.5×、damping 与 frictionloss 各差 11×、
  armature 差 15.5× —— 每一项都差一个数量级
- 反直觉发现：XL330 建模的回差反而更大（±1.0° vs ±0.5°）
- 结论：**没有中间路线** —— 保 XL330（舵机 ¥4500）或换 STS3215
  （等于去做 Open Duck Mini v2）
- **补充同级别舵机横向对比**：飞特 STS3032（20 g / 23.2×12.1×28.5 mm / 0.44 N·m /
  4.8–6 V）尺寸比 XL330 还小、重量相当，但力矩约 85%（同电压口径）且电压上限 6 V；
  SCS0009 仅 11 g 但只有 0.23 N·m（Pollen 自己用在 Amazing Hand 上）
- 结论：空档明确为「18–20 g / ≥0.9 N·m / 7.4 V / 总线」，目前只有 Robotis 一家满足
- **深度评估宇树 S288**（通读官方 11 页手册）：19.5 g / 34×20×23 mm /
  **减速比 288.35:1 与 XL330 完全相同** / M2 固定 / 单线半双工 —— 机械上几乎是平替
- S288 的两个实质升级：**阻抗控制**（τ = τ_ff + k_p·Δp + k_d·Δω）和
  **输出端编码器**（OutPos 13 位）—— 后者可直接消灭回差建模的整套复杂度
- S288 的三个硬约束：电压 12.6 V (3S) vs Microduck 的 7.4 V (2S)；
  总线地址空间仅 0~14 装不下第 16 个设备（IMU 须另走 SPI）；
  **力矩标注存疑**（转子端/输出端两种解读都说不通），已列出向厂商求证的四个问题
- 产出：重写 `docs/执行器选型.md`（106 → 424 行）

### 第 8 批 · X 社区情报与外部验证 ⭐

- 通过 opencli 的 twitter read 命令（search / thread）读取 X 公开帖
- **核心收获：逆向结论获得外部独立验证** —— @tspy 的硬件拆解（169 赞）
  独立列出 Radxa ZERO 3W / RK3566，与本仓库完全一致
- 记录热度数据：官方三条推合计约 860 万浏览；GitHub 三天涨 3.7 倍
- 记录社区已做出的二次开发（R2D2 语音合成、激光笔追踪、翻筋斗、霹雳舞）
- **识别并标注噪音**：大量 meme 币蹭热度；「Microdino」经查回复区
  充斥 scam 指控且 CAD 问题含糊其辞，**判定为不可信，不予引用**
- 明确一个前提：**截至 8/31 市面无实物**，所有公开 teardown 都是推理而非物理拆解
- 产出：`docs/社区动态.md`（150 行）

### 第 7 批 · 官方规格交叉验证 + 社区动态

- 官方 2026-08-27 发布，公布部分规格；与本仓库逆向结果**逐项对照**
- 互相印证：RK3566 / NP-F550 / 8×8 ToF / 宽 140mm 全部对上
- 官方补足：RAM 1GB + 32GB eMMC（**正是 Radxa Zero 3W 的 SKU，反向佐证主控判断**；源码中无佐证，复刻建议 2G/16G）、
  NPU 0.8 TOPS、NFC 双天线
- 逆向独有：主控型号、主总线方案、全部芯片地址与协议
- **发现一处矛盾**：官方标 2 个 IMU，源码里只有 1 个在用（BMI088 标注 dormant）
- 记录官方开源立场：Pollen 明确要求媒体**不要**称其为"开源硬件"（但加了 "for now"）
- 记录社区三个未获回复的 issue（#175 STEP / #173 打印源文件 / #174 电源板原理图）

### 第 6 批 · 硬件方案逆向 ⭐

- 思路：**运行时要驱动真实硬件，就必须写死设备路径、I2C 地址、寄存器偏移、
  波特率和协议 —— 代码即规格书**
- 从 `duck-control/src/{model,imu,bus}.rs`、`deploy/*.dts`、`deploy/robotd.toml`、
  `tof/`、`mediad/` 里逐项挖出完整电控方案
- 产出：`docs/硬件方案逆向.md`（394 行，完整推导）+ `docs/硬件规格速查.md`（270 行，一页纸速查）

### 第 5 批 · 执行器选型

- 整理 BAM M6 配置、三项域随机化范围、回差编码器建模
- 提取 `joints_properties.xml` 里 5 组 BAM 实测标定的原生 PD 参数
- 产出：`docs/执行器选型.md`

---

### 第 14 批 · 按计划推进：exp001 实跑完成 + imu_to_dxl 连接表（2026-09-06）

- **exp001 A/B 真跑完成**（预注册方案 100 迭代 × 64 环境，本机 CPU 各 4 分钟）：
  B（IMU 随机化 OFF）末段 reward 领先（1.014 vs 0.801），其余四指标（摔倒率/速度跟踪误差/
  探索噪声）几乎重合——预注册预案"100 迭代只能得出前期动力学差异"命中。
  随机化结论：**不拖累收敛，代价是训练期 reward 低 ~20%，鲁棒性收益待扰动测试（exp001b 待办）**
- 过程问题与解决（详见构建日志 2026-09-06 四条）：mjlab 训练器无 GPU 崩溃 →
  `CUDA_VISIBLE_DEVICES=""`；默认 wandb 报错 → `--agent.logger tensorboard`；
  TPU 代打被拒 → 两件拆出单独补；引脚编号不确定 → 网络名/引脚名连接表策略
- 新增 `docs/imu_to_dxl-设计包/原理图连接表.md`：网络总表 + 每芯片引脚预算 + EDA 自查清单，
  埋点 LSM6DSV16X CS 拉高、LDO 输入电容 ≥25V 两个易翻车点
- 对比图 `rl-series/assets/exp001-AB对比.png`（五指标 100 迭代真数据）
- **exp001b 扰动测试完成**：对两组 checkpoint 施加 0–15° 相同 IMU 旋转——
  A 最大衰减 -4.6% vs B -6.0%，10° 起 A 反超，但 1–2% 差异在单 seed 噪声内，
  100 迭代尺度不下统计结论；评估工具固化为 `rl-series/scripts/eval_imu_robustness.py`
- **文章 08 升级为实测文**（占位全部替换为真数据）；意外收获：评估网络结构直接
  显示 critic `in_features=76`，为 76 维特权观测再添运行时证据
- **3D 仿真回放搭通**：`rl-series/scripts/capture_rollout.py`（mjlab rgb_array 离屏渲染，
  ASSET_ROOT 跟拍相机）→ A/B 回放 GIF + 关键帧入 `assets/`；交互查看命令
  （`uv run play --viewer native/viser`）写入 rl-series README；
  释疑"亮度 58/255"假警报（黑天空拉低均值，画面本身正常）
- **可视化操作台上线**：`rl-series/scripts/dashboard.py`（http://localhost:8090，纯标准库）——
  状态/按钮/产物画廊，端到端实测按钮触发捕获出片；新增 `serve_play.sh` 一键启动
- **《换舵机重训全流程》手册**（`docs/换舵机重训全流程.md`）：四层影响面判定、
  单舵机台架辨识流程、9 策略↔任务映射与优先级、树莓派两用法、L1–L7 测试金字塔
- **expC 续训中期战报（迭代 336/2199）**：reward 2.10 **达成预注册 H1**；
  fell_over 1.54–1.67（H2 进展中）；回放/长训练完成后补终判
- **《阶梯式采购与验证路线》**（`docs/阶梯式采购与验证路线.md`）：主控缺货时期的执行策略——
  门控式分步（G1 打印定标 → G2 Pi+单舵机 50Hz 控制环 → G3 自制板 16 台总线 → G4 舵机大单），
  长货期件过门控立即下单与调试并行；树莓派定位 = 地面调试台（机载化待 G4 后决策）
- **采购落地（2026-09-07）**：飞特 HL-1910-C001 ×15（¥1500，HLS 恒力 TTL 总线）+ Zero 3W（¥299）
  + 外壳 41 件（¥99），已花 ¥1898，整机预计 ≈¥2460 低于官方售价。
  **换舵机路线正式激活**：官方 ONNX 作废须重训、`bus.rs` 适配层、`imu_to_dxl` 走飞特固件分支、
  打印件舵机仓适配 = 头号验证项——四层影响与到货检查清单见 `docs/物料清单-进度快照.md`"一⁺"节

### 第 13 批 · 复刻总清单 + 测试片补缺（2026-09-06）

- 补上此前缺的**孔径测试片 STL ×3**（M2 孔径阶梯 / Ø22 轴承压入三档 / Ø15 压入三档），
  全部水密、法向一致已验证；生成脚本 `scripts/generate_test_coupon.py`（依赖 shapely+mapbox_earcut，
  用 `uv run --with` 临时环境跑，不污染上游 venv）。踩坑：Ø22.1 的孔放进 20mm 高的板导致几何非法，
  修正为 76×26 板 + 孔心距 24
- 新增 `docs/复刻总清单.md`：汇总打印清单/缺件清单/采购推荐/总成本（地板价 ≈¥3500，
  忠实版 ≈¥3900–4500，对比整机 ¥2900）/替代方案/最低成本路径
- 缺件盘点结论：**打印文件已 100% 齐**（30 种/41 件 + 测试片 3 件）；唯一要画的板仍是
  `imu_to_dxl`（规格已备齐待画 EDA）；电池触点用现成扣板（¥19）顶掉
- 总清单补充：**下单链接速查**（全部淘宝/官方实链聚合）与**打印方式对比**——
  精确用量按逐件体积加权实测为 PLA 299g + TPU 26g；嘉立创代打全机约 ¥85–210
  （PLA 低至 0.2 元/g、1 件起订），结论：没打印机的人代打完胜（别为一只鸭子买 ¥2500 的机器），
  已有 K1C 则钱上打平、看是否要定标学习闭环，推荐测试片+腿部自打、大件可代打
- 代打实价入库（2026-09-06 询价）：嘉立创全机 ¥266、淘宝按重店 ¥99 白色（≈0.33 元/g，
  推算与 299g 用量吻合，大概率 FDM 真价）；总清单已加「¥99 店下单前必核四项」
  （FDM/树脂、41 件还是 30 件、壁数填充、TPU）与「测试片先行」下单纪律

### 第 12 批 · `imu_to_dxl` 设计包 + 固件协议层 ⭐（2026-09-05）

- 高优先卡点「画 `imu_to_dxl` 板」从一句话推进到**可直接开画**的完整输入
- 主机侧预期全部从 Rust 源码逐行核实并标注行号：ID 200（model.rs L78）、
  1 Mbps（L80）、读 124/12（bus.rs L27–28）、主机超时 30ms（bus.rs L49）、
  陀螺 **i16 LE ±500dps 原始计数**（imu.rs L12/L47——修正了此前文档中「12 字节全 fp16」的模糊表述）、
  四元数 fp16 LE（imu.rs L13）、完整诊断块 20 字节（imu.rs L15–16）
- **固件协议层写成纯 C99 并带主机测试：6/6 通过**
  （PING/READ/SYNC_READ 正确应答；非本板帧与 CRC 错误正确沉默；应答 CRC 自洽）
- 产出：`docs/imu_to_dxl-设计包/` —— 设计规格（框图/引脚/时序预算/验收清单）、
  BOM（14 种元件，MPN 级，含「ME6211 耐压不够、须 HT7333」的避坑）、
  firmware/（crc16 + dxl_slave + imu 驱动骨架 + main 骨架 + 主机测试）
- 设计决策：半双工用 SN74LVC1G126 缓冲（OE 下拉默认断开，防上电抢线）而非裸 HDSEL；
  不做电池电压测量（主机读舵机自报电压，已验证）
- 未决：LSM6DSV16X SFLP 初始化序列、G031 AF 复用编号须查手册；
  板框尺寸须对照躯干内腔（cad/）定

### 第 11 批 · 打印就绪检查 + 工艺调整表（2026-09-05）

- **30 种 / 41 件打印件全量体检：全部水密、法向一致，可直接切片** ——
  几何层面推翻了「仿真件切不了」的担忧；真正的风险收敛到公差与壁厚
- 踩坑记录：STL 不合并顶点必误报非水密（trimesh `process=True`）；
  MJCF STL 是米制单位，体积/包围盒须先缩放；碎面判定阈值在米制下产生 6 件误报
- 全机孔位按打印数量加权：过孔 Ø2.2 ×111、沉头 Ø4.4 ×48、攻丝底孔 Ø1.6 ×27
- 产出：`scripts/check_printability.py`（可重跑）、`docs/打印就绪检查.md`（自动生成）、
  `docs/打印工艺调整表.md`（三类孔处理办法 + 孔径测试片方案 + 摆放建议 + 耗材估算约 285g）
- 另建 `复刻关键路径-30天.md`：打印/电路/采购/软件四条依赖链排期

## 关键发现

1. **整机是 M2 螺丝系统。**
   Ø2.2 过孔 ×77、Ø4.4 沉头孔 ×28、Ø1.6 攻丝底孔 ×20。
   Ø2.2 与 Ø4.4 成对出现 = M2 内六角柱头的过孔+沉孔组合。
   交叉验证：`xl330.stl` 自身是 Ø2.0×4 + Ø1.6×8，与 XL330 的 M2 安装孔一致。
   结构件过孔约 **146 个**。

2. **是 15 个舵机，不是 14 个。**
   `xl330` 网格在整机 MJCF 中被引用 **15 次**。14 个进策略动作空间
   （左腿 5 + 颈头 4 + 右腿 5），第 15 个驱动喙/下颚，走 `passive_*` 连杆。
   这与官方 README 的 "15 servos" 一致 —— 只数关节列表会漏掉。

3. **头部占整机四分之一重量。**
   躯干 199g，头部总成 189g，整机 737g。重心很高，
   这解释了为什么它的行走策略难训。

4. **回差建模是 sim2real 的关键细节。**
   真实舵机磁编码器在齿轮间隙的**输出侧**，固件位置环闭环在
   `主关节角 + 回差角` 上；舵机在死区空转时测到的位置不变，PD 误差也不变。

5. **自己造比买贵。**
   15 个 XL330 按渠道从 $359（ROBOTIS 国际站）到 €629（MyBotShop）不等，
   即从略低于到远超整机 $399 售价。核价见 BOM.md。

6. **⭐ 主控是市售模块，不是定制载板 —— 此前判断有误。**
   （2026-08-31 补充：此结论已获 X 上 @tspy 的独立拆解验证）
   设备树里写死 `compatible = "radxa,zero-3w", "rockchip,rk3566"`，
   就是市面上能买到的 **Radxa Zero 3W**（Pi Zero 形态，65×30mm，与 STL 吻合）。
   这直接推翻了「电控是硬墙」的结论。

7. **IMU 挂在 Dynamixel 总线上，不走 I2C。**
   自制 `imu_to_dxl` v2 板：LSM6DSV16X，总线 ID 200，寄存器 124，12 字节块
   （陀螺 6 字节 + SFLP 四元数 fp16 6 字节）。和 15 个舵机在**同一次 sync_read**
   里读回，零额外总线开销，主机不用跑姿态融合。

8. **没有电量计，没有 ADC。**
   电池电压直接读舵机通过 Dynamixel 报告的自身供电电压。
   所以 6.6–8.2V 是「带载可用区间」而非电芯量程。复刻时**不需要设计任何电池监测电路**。

---

## 决策记录

| 决策 | 结论 | 理由 |
|---|---|---|
| 做 Microduck 还是 Open Duck Mini v2 | **做 Microduck** | 用户明确要 Microduck 本身。Open Duck Mini v2 虽然全套开源（BOM/CAD/STL/装配指南齐全），但那是另一台机器人 |
| 仓库公开还是私有 | **公开** | 用户选择。CC BY-NC-SA 允许转发，已配好署名、同协议、非商用声明 |
| 是否把 6 个上游仓库一起打包 | **不打包** | 重新托管别人的代码不合适，且会丢失上游更新。改用 `scripts/fetch_upstream.sh` + 链接<br>（2026-09-04 补充：`print/` 是有意的例外 —— 单件 STL 是复刻者最需要能在网页上逐个查看的东西，CC BY-NC-SA 允许再分发，已在 NOTICE.md 声明） |
| 许可证 | **双协议** | `scripts/` 原创 → Apache-2.0；`assembly-drawings/` `cad/` 是 CC BY-SA-NC 衍生作品 → 依 ShareAlike 沿用同协议 |
| 遇到 PCB 这堵墙怎么办 | **机械照抄 + 电控自建** | 100% 复刻不可能。用户表示能自己做 PCB，所以这条路可行 |

---

## 下一步待办

### 优先级 高
- [x] **画 `imu_to_dxl` 板** —— **原理图与 PCB 都已完成**（2026-09-07）。
      STM32G031F8P6 + LSM6DSV16X + SN74LVC2G241 半双工缓冲；
      45 × 22 mm 双层板，底层整片 GND，22 个网络全通、DRC 0 违规。
      **未打样、无实物验证** → [工程与复查结果](hardware/imu_to_dxl/)
- [ ] **`imu_to_dxl` 打样验证** —— 下单前先跑器件标准化、复核丝印；
      连接器高度（直插 8 mm vs 躯干内腔）需用 STEP 在装配体里确认
- [x] ~~**PCB 板框反推**~~ —— **已作废**：官方 KiCad 工程与 Gerber 直接提供精确板框、
      孔位与连接器开口，无需从 STL 反推
- [ ] **决定 HAT 板做不做** —— 不要录音/喇叭的话可完全省略，
      ToF 直接挂 i2c3，电源用现成 UBEC
- [ ] **打印孔径测试片并把补偿值回填构建日志** —— 全机 111 过孔/48 沉头/27 攻丝
      的实际配合全靠它定标（方案见 docs/打印工艺调整表.md 第二节）

### 优先级 中
- [x] ~~英文化~~ **已完成**：硬件方案逆向 / 执行器选型 / 紧固件反推 三份全部英文化，
      加上 README 共 4 份双语。`社区动态.md` 与 `PROGRESS.md` 不翻 ——
      前者时效性强会过期，后者是内部进度
- [x] ~~**STL 可打印性检查**~~ **已完成**（第 11 批）：30 种/41 件全部水密、法向一致，
      可直接切片 → `docs/打印就绪检查.md`（脚本可重跑）
- [x] ~~**打印工艺评估**~~ **已完成**（第 11 批）：三类 M2 孔处理办法 + 孔径测试片方案
      → `docs/打印工艺调整表.md`；实测定标待打印后回填构建日志
- [ ] **走线通道分析** —— 从装配体的内部空腔反推可行走线路径

### 优先级 低
- [ ] **控制软件方案** —— Rust 运行时绑定 RK3566，评估移植成本
      vs 用 Python 重写控制循环
- [ ] **策略重训** —— 换电控后官方 ONNX 失效，需用 `microduck_rl` 重训
      （需 CUDA GPU，或用 `--hf-jobs` 跑在 HuggingFace 上）

---

## 风险与已知局限

1. **仿真 STL ≠ 可打印工程件。** 仿真只保证外形与惯量，不保证配合公差、
   螺纹孔、热熔螺母座、走线空间。直接打印大概率装不起来。
2. **紧固件是反推的，不是图纸。** 螺丝长度按孔深推算，是区间不是实测值。
   打印收缩还会改变实际孔径（FDM 上 Ø2.2 通常偏小 0.1–0.3mm）。
3. **`imu_to_dxl` 板需自绘。** 全网无公开工程，只能照还原出的协议自己设计。
   （HAT 板官方已开源，含 Gerber，**不构成阻塞**。）
4. **官方策略不可迁移。** 换电控后 9 个 ONNX 全部失效，必须重训。
5. **非商用限制。** 所有几何衍生内容受 CC BY-SA-NC 约束，不得用于商业产品。

---

## 文件索引

| 路径 | 内容 |
|---|---|
| `README.md` | 项目总览、装配结构、关节参数、可行性分析 |
| `PROGRESS.md` | 本文档 |
| `NOTICE.md` | 署名与来源 |
| `assembly-drawings/` | 7 张装配图 |
| `cad/` | 16 个 STL（整机 + 15 部件）+ 零件对照表 |
| `docs/紧固件反推.md` | M2 螺丝系统、采购量、轴承规格 |
| `docs/执行器选型.md` | XL330 参数、BAM M6、5 组标定 PD、回差建模 |
| `docs/硬件规格速查.md` | 一页纸硬件规格表 |
| `docs/硬件方案逆向.md` | 电控方案完整推导与证据 |
| `docs/社区动态.md` | X / GitHub 情报、外部验证、噪音与风险 |
| `docs/复刻总清单.md` | 打什么/缺什么/买什么/总成本/最省路径（汇总层） |
| `print/测试片/` | 孔径与轴承定标件 STL ×3 + 图例（打印前必打） |
| `docs/打印就绪检查.md` | 41 件打印件体检报告（脚本自动生成，可重跑） |
| `docs/打印工艺调整表.md` | 孔径补偿、测试片方案、摆放与耗材估算 |
| `docs/imu_to_dxl-设计包/` | 自绘板规格 + BOM + 固件（协议层已测试 6/6） |
| `复刻关键路径-30天.md` | 硬件线 30 天排期（打印/电路/采购/软件四链） |
| `docs/hole_analysis.json` | 孔扫描原始数据 |
| `scripts/` | 拉上游 / 渲染 / 导出 CAD / 扫孔 / 打印体检，5 个脚本 |

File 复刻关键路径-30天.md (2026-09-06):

# 复刻关键路径 · 30 天（2026-09-05 → 10-04）

> 与 `rl-series/30天计划.md`（RL/公众号线）配套：**这条是「鸭子活过来」的硬件线**。
> 两条线每周交汇一次：硬件的每个里程碑都喂给公众号一篇文章，训练线的每个实验都为真机部署铺路。
> 标签：🔨 动手 ｜ 🛒 采购 ｜ 💻 电脑上做 ｜ ✋ 必须人在场

## 关键路径总览（决定整体进度的只有四条依赖链）

```
A. 结构件: 测试片 → 定孔径补偿 → 批量打印 41 件 → 试装
B. 电路:   imu_to_dxl 原理图/PCB → 打样(3-5天) → 贴片烧录 → 单板自测 → 总线联调
C. 采购:   舵机×15(最慢!) → 主控/电池/传感器 → 到货验收
D. 软件:   Radxa 刷 Armbian → 三个必踩的坑 → 官方 Rust 运行时跑通 → 装 ONNX → 遥控
```

**第一天就该下单的**（等货期）：🛒 XL330 舵机 ×15（国际到货 1–3 周，见 BOM.md 核价）、🛒 Radxa Zero 3W、🛒 电池/IMX219/VL53L8CX/LSM6DSV16X/HT7333/SN74LVC1G126/STM32G031F8P6（按 `docs/imu_to_dxl-设计包/BOM.md` + `docs/电控采购清单.md`）。

---

## 第 1 周（D1–7）：测试片定标 + imu_to_dxl 开画 + 发起打样

| 天 | 动作 | 产出 |
|---|---|---|
| D1 | 💻 读 `docs/打印就绪检查.md` + `docs/打印工艺调整表.md`；🔨 **打孔径测试片**（调整表第二节，30 分钟） | 测试片 |
| D2 | ✋ 测试片实测：M2 过/攻丝/沉头、轴承 Ø22/Ø15 三档，**把补偿值写进构建日志** | 全机孔径补偿定标 |
| D3 | 💻 照 `docs/imu_to_dxl-设计包/设计规格.md` 在嘉立创 EDA 画原理图（BOM 元件 14 种）；【待核对】项对着 datasheet 填 | 原理图 v1 |
| D4 | 💻 PCB 布局（2 层）；板框/安装孔对照 `cad/` 躯干内腔定尺寸 | PCB v1 |
| D5 | ✋ 检查 PCB v1（引脚网络表对照规格第四节）→ 🛒 **下单打样**（3–5 天货期） | 打样单 |
| D6 | 🔨 开始批量打印：先打**腿部件全套**（试装过的件最稳） | 首批结构件 |
| D7 | 💻 RL 线交汇：跑 exp001 A 组；构建日志补测试片实测数据 | 公众号素材 |

**周退出标准**：孔径补偿定标完成；PCB 已下单；腿部打印件在手。

## 第 2 周（D8–14）：批量打印 + 板子回来 + 单板点亮

| 天 | 动作 | 产出 |
|---|---|---|
| D8–9 | 🔨 打印头壳/躯干壳/脚（耗材大头，约 54 cm³）；按调整表第四节摆件 | 结构件大部分 |
| D10 | ✋ PCB 到货 → 贴片（手焊：0603 + TSSOP20 + SC-70，热风）→ SWD 烧录固件骨架 | 点亮的板 |
| D11 | 💻 补固件两个 TODO：HAL 初始化（I2C/UART）+ LSM6DSV16X 初始化序列（datasheet） | 固件 v1 |
| D12 | ✋ 单板自测（规格第七节 1–2 步）：PING → READ 124 → 晃动看陀螺/四元数变化 | 板子出活数据 |
| D13 | 🔨 继续打印；💻 RL 线：exp001 B 组 + 对比图 | exp001 结论 |
| D14 | 💻 周复盘 + 公众号（硬件线第一篇：测试片与孔径补偿实测） | 文章存稿 |

**周退出标准**：41 件打完 ≥80%；imu_to_dxl 单板出真实 IMU 数据。

## 第 3 周（D15–21）：总线联调 + 躯干装配 + Radxa 起飞

| 天 | 动作 | 产出 |
|---|---|---|
| D15–16 | 🔨 装配躯干底座 + 15 舵机骨架（若舵机已到）：装 IMU 板进躯干，走 EH 线菊花链 | 躯干总成 |
| D17 | ✋ **总线联调**：Radxa `/dev/ttyS2` 一次 sync_read 读回 16 台设备（验收清单第 3 步） | 联调通过 |
| D18 | ✋ mask `serial-getty@ttyS2`、i2c3/FUSB302 引脚取舍、NPU overlay（README 三个必踩的坑逐个过） | 系统底座 |
| D19–20 | 💻 编译部署官方 Rust 运行时（`deploy/` + robotd），装官方 ONNX；🛒 补缺件 | 运行时上机 |
| D21 | 💻 RL 线：发起 GPU 长训练（或 `--hf-jobs`）；公众号硬件线第二篇（总线联调） | 文章存稿 |

**周退出标准**：`robotd` 能读全总线；躯干立得起来。

## 第 4 周（D22–30）：整机装配 + 上电 + 复盘

| 天 | 动作 | 产出 |
|---|---|---|
| D22–24 | 🔨 装配双腿 + 头颈（构建日志逐件记录问题） | 整机 |
| D25 | ✋ 上电姿态检查（不装腿先空跑 HOME 姿态）；电池电压经舵机自报验证 | 安全上电 |
| D26–27 | ✋ 装官方 ONNX 走路策略，手柄遥控首走（摔了照实记录——那是文章 11 的素材） | **鸭子走路** |
| D28 | 💻 对照 rl-series 文章 11 逐项填「仿真 vs 真机」差异表 | sim2real 实测 |
| D29 | 💻 复盘：构建日志终稿 + 反推数据 vs 实测全表（M2/沉头/攻丝/外形 144×141×264） | 验证结论 |
| D30 | 💻 下一周期计划（重训 or 优化走姿 or 轮滑模式）；公众号收官篇 | 系列完整 |

**周退出标准**：整机至少完成「站立 + 遥控行走尝试」；构建日志无空白行。

---

## 风险与退路

| 风险 | 退路 |
|---|---|
| 舵机货期拖过 2 周 | 先做 B/C/D 链（板子、Radxa、固件），装配后置 |
| imu_to_dxl 首板翻车 | BOM 极简 + 协议层已测试，改板成本低；留 v2 打样预算 |
| 打印件装不上 | 测试片已提前定补偿；个别孔钻修是预期内的（构建日志已验证一次） |
| 官方 ONNX 在复刻件上表现差 | 回到 rl-series：用复刻实测差异表调整 DR 后重训（实验方法论已就绪） |

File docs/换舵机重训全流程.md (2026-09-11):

# 换舵机 / 换零件 → 调整 → 重训 → 部署 → 验证：全流程手册

> 回答一组连环问题：换了舵机厂家（或其他零件）后，**要改哪些东西？怎么重训 9 个 ONNX？
> 怎么测试（是否先测一只舵机）？树莓派和官方主板分别怎么用？整体思路是什么？**
> 事实基线：上游 `29e887e`；标签：`【已验证】`源码/本机实验核实 ｜ `【推断】`待实测 ｜ `【未完成】`未验证

---

## 0. 一张图看懂改动传播链

```
换舵机（硬件改动）
  ├─① 机械层   → 打印件舵机仓/孔位/MJCF 几何（外形变了才要改）
  ├─② 电气层   → 供电电压窗口 / 电流 / 接口线序
  ├─③ 通信层   → 协议（Dynamixel V2 / 飞特 / 宇树私有）+ 波特率 + ID 空间
  └─④ 动力学层 → 力矩/速度/回差/摩擦/PD 特性 —— 这层决定策略能不能直接用
                        │
        ②③④ 全部汇入 ▼
   MJCF 执行器模型（BAM 参数 + 域随机化范围）       ←── 单舵机台架辨识提供数据
                        │
                        ▼
   重训策略（9 个任务各自一次训练）──产出──▶ 9 个新 ONNX
                        │
                        ▼
   部署（官方 Rust 运行时 / 树莓派）──▶ 测试金字塔逐级验证
```

**总原则：改动是逐层传导的，上一层没锁死就别动下一层。** 每层的"改不改"由判定表决定（§1）。

---

## 1. 换舵机影响面判定表（先做这张表，再动手）

| 层 | 关键问题 | 若不兼容要改什么 |
|---|---|---|
| **① 几何** | 外形/安装孔/输出轴与 XL330（20×34×26，M2）一致吗 | 打印件舵机仓重画 + MJCF 网格替换 + 质量惯量重算 |
| **② 电气** | 电压窗口覆盖 6.6–8.2V（官方超压工况）？堵转电流 HAT/UBEC 供得起吗 | 供电架构（电池节数/UBEC/HAT 取舍）重做 |
| **③ 通信** | 协议是 Dynamixel V2？1Mbps？ID 空间够 16 台？回延迟寄存器存在吗 | 运行时写新控制器（飞特走 rustypot 现成模块）；`imu_to_dxl` 固件改协议分支（双协议设计已备） |
| **④ 动力学** | 力矩≥0.5N·m 量级、速度、回差、摩擦特性接近 | **执行器模型重辨识 + 策略必须重训**（官方 ONNX 作废） |

> 四层全兼容才谈得上"不改模型直接用"——当前市场没有这样的便宜货（见[执行器选型](执行器选型.md)）。
> 所以现实路径必然是：**逐层适配 + 重训**。本手册就是这条路的作业指导书。

---

## 2. 第一步永远是：单舵机台架测试（对，先测一只）

买 1–2 只新舵机，15 只大单之前把下面做完。工具：FE-URT-1 调试板（¥45，已在采购清单）+ USB 转 TTL + 可调电源。

### 2.1 电气与通信（半天）

| 测试 | 方法 | 通过标准 |
|---|---|---|
| 协议连通 | 调试板按其协议发 PING/读寄存器 | 能 ping 通、能写读位置 |
| 波特率 | 1Mbps 下收发 1000 包无 CRC 错 | 误包率 ≈0 |
| 电压窗口 | 6.6V / 7.4V / 8.2V 各跑 10 分钟 | 无过热保护、行为一致 |
| 堵转电流 | 堵转 2 秒读电流（电源显示） | 峰值 < 供电预算（15 只同启是大头） |

### 2.2 动力学辨识（一天，重训数据全从这来）

| 测什么 | 怎么测 | 进哪个参数 |
|---|---|---|
| **PD 阶跃响应** | 给位置阶跃（如 30°），示波/高频回读画出响应曲线。台架课 6（`hl2915_bench.py 6`）可自动完成：改 21/22 号做阶跃、50Hz 录 CSV、直接出超调/稳态误差/整定指标 | `kp / kd`（BAM 的 stiffness/damping） |
| **堵转力矩-速度曲线** | 逐速度点堵转读力矩（带力矩反馈的舵机可直接读） | `forcerange`、力矩上限 |
| **回差** | 从正反两方向趋近同一目标位，读差值 | `backlash` 模型（mjlab 有 `backlash.py` 现成框架） |
| **摩擦** | 匀速转动测维持力矩 | `friction_base / friction_viscous` |
| **转子反射惯量** | 空载加减速拟合 | `armature` |

> 这一步的产出是一组 **BAM 参数**（对照 `robot/microduck/constants.py` 里官方那组）。
> 官方的参数也是这么测出来的（`joints_properties.xml` 里 5 组实测标定）——复刻者做一样的事。

---

## 3. 改仿真模型（全部在 `microduck_rl` 仓库内）

| 改什么 | 文件 | 说明 |
|---|---|---|
| 执行器参数 | `src/mjlab_microduck/actuator/friction_dr_bam.py` 配置 + `robot/microduck_constants.py` | 用 §2.2 的辨识值替换官方 BAM 参数；**注意 vin_range 按新舵机额定改**（官方是 6.5–8.2 超压特例，勿照抄） |
| 回差建模 | `tasks/backlash.py`（框架现成） | 填新舵机实测回差角 |
| 域随机化范围 | `tasks/microduck_velocity_env_cfg.py` L28–53 | 新舵机出厂差异大 → 范围放大；个体一致 → 可收窄。**范围 = 你的台架实测离散度** |
| 几何（仅当外形变了） | `robot/microduck/assets/` 网格 + 打印件 | 质量惯量随新网格重算；打印件连锁修改 |
| **不动的** | obs 61 维 / action 14 维 / reward 结构 / 课程表 | 关节还是那 14 个，接口规格不变（运行时省大改） |

验证改对了没有：跑 5 迭代冒烟，确认 obs/action 维度不变、无 NaN、reward 量级正常——再进训练。

---

## 4. 重训 9 个 ONNX：方法与优先级

### 4.1 先分清 9 个策略是什么

9 个 ONNX = **9 个技能，各自独立训练一次**（同一套配方，不同任务配置），每个仅 ~775 KiB：

| 官方策略 | 对应任务（`uv run list-envs` 里的 ID） | 优先级 |
|---|---|---|
| `alpha_walking` | `Mjlab-Velocity-Flat-MicroDuck` | ⭐ **第一个训**（核心技能） |
| `alpha_stand` | VelStand / SitStand 系 | ⭐ 第二（站立是安全兜底） |
| `alpha_sitstand` | `Mjlab-SitStand-Flat-MicroDuck` | 与站立可并行 |
| `alpha_ground_pick` | `Mjlab-GroundPick-Flat-MicroDuck` | 按需 |
| `ball_kick_left / right` | `Mjlab-BallKick-Flat-MicroDuck`（左右脚两次训练） | 按需 |
| `roller` / `roller_crouch` | `Mjlab-Velocity-Flat-MicroDuck-Rollers` / `RollerCrouch` | 做轮滑才训 |
| `roulade` | `Mjlab-Roulade-Flat-MicroDuck` | 玩乐技能最后 |

> 映射关系标注：任务↔策略文件名的对应为**推断**（依据任务语义与命名），以导出产物与运行时清单最终核对为准。

### 4.2 训练方法（三档算力）

| 档 | 命令 | 量级 | 用途 |
|---|---|---|---|
| 调试档（本机 CPU） | `CUDA_VISIBLE_DEVICES="" uv run train <任务ID> --env.scene.num-envs 64 --agent.max_iterations 100` | 4 分钟/百迭代 | 验证改的模型能跑、曲线方向对 |
| **正式档（GPU）** | `uv run train <任务ID> --env.scene.num-envs 4096 --agent.max_iterations <数千~数万>` | 数小时~天/技能 | **出可部署的策略**；无卡用 `--hf-jobs`（官方内置） |
| 批量档 | 9 个任务逐个跑（或 HF Jobs 排队） | ×9 | 全家桶 |

判断"训够了"的信号（对每个技能）：`fell_over` 稳定低位、`error_vel` 平台化、`mean_std` 收敛到低位——
和官方曲线对比（wandb/文档若公开）或以回放行为为准。**训练量参考：官方配方上限是 4096 环境 × 5 万迭代；
走路通常在数千迭代、10⁷–10⁸ 步量级出现**（expC 续训正在实证 CPU 量级的下限）。

### 4.3 导出与校验

- 训练目录自动生成 `.onnx`；**每次导出后跑一遍校验**：`rl-series/scripts/inspect_onnx.py` 确认 `obs[1,61] / actions[1,14]`；
- 9 个文件命名对齐运行时清单（`alpha_*` / `ball_kick_*` / `roller*` / `roulade`），放进更新包结构即可被 `updaterd` 分发。

---

## 5. 部署：树莓派 vs 官方主板（Radxa）

### 5.1 官方同款路线（Radxa Zero 3W）——零移植

- 软件（Armbian + Rust 运行时 + 设备树 overlay）原样跑：`deploy/` 脚本按官方流程走；
- **换舵机只影响 `duck-control/src/bus.rs` 以下的控制器层**：Dynamixel 兼容舵机 → 改 ID 表即可；
  飞特协议 → 换 rustypot 飞特模块（通信层现成）；宇树私有协议 → 写新控制器；
- 官方 HAT（已开源 Gerber）直接打样或按[总清单](复刻总清单.md)用转接板+UBEC 替代。

### 5.2 树莓派路线——两种用法

| 用法 | 做法 | 评价 |
|---|---|---|
| **地面调试台（推荐起步）** | 树莓派 + USB-TTL/FE-URT-1 接舵机，跑 rustypot/python 脚本做 §2 台架测试、批量写 ID/标定 | 零移植，第一天就能用 |
| **机载主控（要移植）** | 官方 HAT 物理上就是 Pi 40-pin HAT，可插 Pi 4/5；但要自己搞定：① UART 引脚复用 + 1Mbps（Pi 的 PL011 支持，需 dtoverlay 并关串口控制台）② i2c3→Pi 的 i2c 引脚映射 + TLV320AIC3104 音频 overlay ③ 摄像头 IMX219（Pi 原生支持 ✓）④ `duck-control` 交叉编译 aarch64 + 设备路径/实时优先级调整 ⑤ onnxruntime 用 Pi 的 aarch64 wheel（`duck_detect` 走 CPU ✓，RKNN 的 NPU 检测模型在 Pi 上不可用） | 可行，工作量 = 一次中型移植【推断，未验证】 |

> 结论：**官方主板路线是"改舵机"的最短路径**；树莓派先当调试台，机载化等走路跑通后再立项。
> 另注：官方 HAT 的 `imu_to_dxl`/音频依赖特定 i2c/i2s 控制器编号，Pi 上设备树要重写——这是移植工作量的主要来源。

---

## 6. 测试金字塔（新模型上线顺序，逐级收紧风险）

```
L1 单舵机台架        §2 —— 辨识数据本身（在买 15 只之前）
L2 仿真评估          新执行器模型下：旧策略跑 100 迭代评估 → 量化退化幅度（预期大，作为基线证据）
L3 重训后仿真评估    新策略回放（capture_rollout.py）+ 五指标曲线 —— 仿真内先"会走"
L4 总线联调          全部 15+1 台设备一次 sync_read 全回（duck-control 自检）
L5 吊装/悬空测试     策略上真机但整机吊起：验证关机序、限位、急停、无负载动作
L6 软垫地面遥控      跌落无损伤环境里试走；记录电流/温升/噪音
L7 平地验收          对照官方行为清单：站立→走→转→坐→拾取，逐技能验收
```

每级的**验证指标**：L3 用仿真五指标（reward/fell_over/误差/std）；L4 用误包率；L5–L7 用
"行为清单 + 电流/温度/机械噪声 + 视频留档"，全部回填[构建日志](../构建日志.md)的验证表。

---

## 7. 高频坑清单（每条都来自本仓库已发生的教训）

1. **换执行器后官方 ONNX 一定作废**——训练内嵌了执行器模型，"看起来差不多"不够；
2. **随机化范围是按官方舵机的离散度定的**，换舵机不重定范围 = 白随机；
3. **回差/摩擦实测数据比厂商标称可靠**——宇树 S288 的力矩标注风波就是前车之鉴；
4. obs 布局（61/76/14）是策略指纹，**动布局 = 三处同步改**（仿真/导出/运行时）+ 全部断言重跑；
5. 真机首跑永远先 L5 吊装——`robotd` 的 `safety.rs` 有保护，但物理世界没有 undo。

---

*配套实验：`rl-series/experiments/`（expC 续训正在实证"训练量→步态"的关系）·
控制台：`python3 rl-series/scripts/dashboard.py` → http://localhost:8090*

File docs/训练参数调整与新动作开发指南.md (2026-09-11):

# Microduck 训练参数调整与新动作开发指南

> 给第一次接触机器人强化学习的人：先学会运行和观察，再改一个参数；先让仿真可靠，再谈新动作；先辨识一只舵机，再训练整机。
>
> 本文按本地源码逐项核对。训练仓基线为 `microduck_rl` 的 `develop@29e887e`。当前工作区另有一处本地实验改动：走路任务的 `air_time.threshold_min` 从上游值 `0.125 s` 改为 `0.04 s`。本文会同时标出二者，不把本地实验值冒充上游默认值。

---

## 1. 新手应该分哪些阶段

不要从“写一个跳舞奖励函数”开始。推荐按下面六级推进。每一级都以前一级的产物为输入。

| 阶段 | 建议时间 | 只做什么 | 交付物 | 通过标准 | 暂时不要碰 |
|---|---:|---|---|---|---|
| 0. 建立地图 | 半天 | 看懂三个仓库、任务列表和训练命令 | 一张自己的文件地图 | 能说清训练、部署、舵机模型各在哪 | 奖励权重、PPO 参数 |
| 1. 跑通现有策略 | 1 天 | 列任务、5 次迭代冒烟、回放已有 checkpoint | 命令和回放录像 | 能稳定复现，不出现 NaN/维度错误 | 新动作、真机上电 |
| 2. 看懂一次决策 | 1～2 天 | 理解 61 维观测、14 维动作、50 Hz 控制 | 手写一张输入输出表 | 能解释一个动作怎样变成关节目标 | 改观测维度 |
| 3. 单变量实验 | 2～4 天 | 每次只改一个命令、奖励或随机化参数 | A/B 实验记录 | 能从曲线和回放解释因果 | 同时改五六个参数 |
| 4. 新动作 | 1～2 周 | 从最接近的现有任务复制，先做走快，再做舞蹈 | 独立任务、测试、checkpoint | 冒烟、训练、回放、导出均通过 | 直接上真机 |
| 5. 换舵机 | 1～3 周 | 单舵机台架、BAM 拟合、协议适配、重训 | 参数 JSON、总线后端、新 ONNX | 仿真与台架响应接近 | 买齐 15 只后才第一次测 |
| 6. 真机闭环 | 持续 | 吊装、软垫、低增益、逐技能验收 | 测试记录与安全边界 | 温度、电流、时序、动作均达标 | 无保护直接落地跑 |

### 1.1 你现在最适合做什么

你已经有 Radxa Zero 3W，但还不需要让它承担训练。近期按这个顺序最稳：

1. 在 Mac 上跑通任务列表、短训练和浏览器回放；
2. 用现有走路任务做一次“只改一个参数”的 A/B；
3. 学会读 observation、reward、curriculum 三张表；
4. 做一个仿真专用的“走快”任务；
5. 再做有节拍的摇摆/踏步舞蹈；
6. Radxa 先用于 Linux、串口和单舵机台架，最后才加载 ONNX 控制整机。

阶段 3 以前，完全不需要买齐舵机，也不需要修改 Rust 总线代码。

---

## 2. 三个代码层分别负责什么

本项目不是一个仓库包办所有事情。

```text
microduck_rl（训练）
  机器人 MJCF + BAM 执行器 + 任务/奖励/PPO
                    │ 导出 ONNX
                    ▼
microduck（运行时）
  61 维观测 → ONNX → 14 维动作 → 安全处理 → 舵机总线
                    ▲
                    │ 自定义舵机参数 JSON
bam（执行器辨识）
  单舵机实测日志 → 拟合电机、摩擦、惯量、回差相关参数
```

### 2.1 训练仓 `upstream/microduck_rl`

| 位置 | 中文含义 | 什么时候看 |
|---|---|---|
| `src/mjlab_microduck/tasks/microduck_*_env_cfg.py` | 每个技能的“实验配方” | 改命令、奖励、随机化、课程、PPO |
| `src/mjlab_microduck/tasks/mdp.py` | 自定义观测、命令、奖励、事件、课程函数 | 新增行为逻辑 |
| `src/mjlab_microduck/tasks/__init__.py` | 任务注册表 | 新增任务 ID |
| `src/mjlab_microduck/robot/microduck_constants.py` | HOME 姿态、BAM 舵机、机器人变体 | 换舵机、改站姿、选模型 |
| `src/mjlab_microduck/robot/microduck/` | MJCF、网格、关节和碰撞 | 改机械结构、质量、惯量、限位 |
| `src/mjlab_microduck/actuator/friction_dr_bam.py` | BAM 摩擦随机化和回差编码器 | 理解执行器，不是普通 PD |
| `tests/test_*_cfg.py` | 配方不变量测试 | 每次新增任务都应照着写 |
| `scripts/export.py` | checkpoint → ONNX | 正式导出，带上观测归一化 |
| `scripts/infer_policy.py` | CPU MuJoCo 部署预演 | 上真机前复核 |

### 2.2 真机运行时仓库根目录

| 位置 | 中文含义 | 换舵机时的作用 |
|---|---|---|
| `duck-control/src/io.rs` | 硬件抽象接口 `RobotIo` | 新协议后端应实现这个接口 |
| `duck-control/src/bus.rs` | 当前 Dynamixel XL330 总线实现 | 飞特等协议需要替换/新增实现 |
| `duck-control/src/model.rs` | 15 个 ID、HOME、波特率、寄存器 | ID、零位、协议参数来源 |
| `duck-control/src/obs.rs` | 61 维观测和 14→15 动作映射 | 训练与真机的最高风险契约 |
| `robotd/src/control.rs` | 推理、动作缩放、低通、技能切换 | 部署动作处理必须与训练匹配 |
| `deploy/robotd.toml` | 每台机器的运行参数模板 | 增益、动作尺度、安全阈值 |

### 2.3 BAM 仓库 `bam`

BAM 不是“给 MuJoCo 填一个最大扭矩”。它从位置误差经过固件位置环、电压、电流、反电动势，再计算力矩和摩擦。换舵机时，真正应该替换的是实测拟合出的 BAM 参数。

---

## 3. 先理解这些强化学习术语

| 源码名 | 新手解释 | 本项目例子 |
|---|---|---|
| Environment / `EnvCfg` | 训练世界的完整规则 | 地面、机器人、传感器、奖励、终止 |
| Observation | 策略能看到的信息 | IMU、关节角、关节速度、上一动作、命令 |
| Action | 策略每 20 ms 输出的数字 | 14 个相对 HOME 的关节位置偏移 |
| Command | 人希望机器人完成什么 | 前进速度、转速、头部姿态、身体姿态 |
| Reward | 告诉策略什么行为更好 | 速度跟踪、直立、抬脚、平滑 |
| Penalty | 对坏行为扣分 | 滑脚、碰撞、动作突变 |
| Termination | 何时结束并重置当前 episode | NaN、超时、摔倒或动作完成 |
| Event | 启动、重置或定时发生的变化 | 随机质心、推一下机器人 |
| Domain randomization / DR | 让每个仿真世界略有不同 | 电压、摩擦、质量、编码器偏差 |
| Curriculum | 先易后难地调整训练规则 | 逐渐加大扰动、扩大头部命令 |
| PPO | 更新策略网络的方法 | 当前所有任务使用的算法 |
| Checkpoint | 可继续训练的 `.pt` 快照 | `model_12500.pt` |
| ONNX | 真机只负责推理的模型文件 | 输入 61，输出 14 |
| Sim-to-real | 仿真策略迁移到真机 | 参数、时序、接口必须尽量一致 |

奖励不是动作脚本。你没有告诉鸭子“先抬左脚再抬右脚”，而是告诉它“跟上目标速度、别倒、脚别拖地、动作别太抖”，PPO 自己搜索出动作。

---

## 4. 61 维输入与 14 维输出是不能随便动的契约

当前所有 alpha 策略使用同一个布局：

| 索引 | 宽度 | 内容 |
|---:|---:|---|
| 0～2 | 3 | 躯干坐标系角速度 |
| 3～5 | 3 | 躯干坐标系投影重力 |
| 6～19 | 14 | 相对 HOME 的关节角，嘴巴除外 |
| 20～33 | 14 | 关节速度，嘴巴除外 |
| 34～47 | 14 | 上一次策略原始动作 |
| 48～50 | 3 | `vx, vy, yaw_rate` |
| 51～54 | 4 | `neck_pitch, head_pitch, head_yaw, head_roll` |
| 55～60 | 6 | 身体 `x, y, z, roll, pitch, yaw` 命令槽 |

动作顺序是：

```text
0..4   左腿：hip_yaw, hip_roll, hip_pitch, knee, ankle
5..8   颈头：neck_pitch, head_pitch, head_yaw, head_roll
9..13  右腿：hip_yaw, hip_roll, hip_pitch, knee, ankle
```

真机有 15 只舵机；第 10 个物理槽位是嘴巴，策略不会输出它。`duck-control/src/obs.rs` 使用同一个映射完成读取和回填。

新技能如果暂时用不到某个命令槽，应保留并填零或极小“存活范围”，不要删除它。否则新 ONNX 不能与现有运行时热切换。

---

## 5. 第一次跑通：Mac 上只做这四件事

进入训练仓：

```bash
cd /Volumes/dev/dev/microduck/microduck-replica/upstream/microduck_rl
uv sync
uv run list-envs | rg MicroDuck
```

先做 5 次迭代的配置冒烟：

```bash
CUDA_VISIBLE_DEVICES="" uv run train Mjlab-Velocity-Flat-MicroDuck \
  --env.scene.num-envs 64 \
  --agent.max_iterations 5
```

已有 checkpoint 可用浏览器 viewer 回放：

```bash
CUDA_VISIBLE_DEVICES="" uv run play Mjlab-Velocity-Flat-MicroDuck \
  --checkpoint-file logs/rsl_rl/velocity/2026-09-08_22-55-20_expE-gait-ramp/model_12500.pt \
  --viewer viser \
  --num-envs 1
```

macOS 上优先用 `--viewer viser`。正式的 4096 并行环境训练应使用 NVIDIA CUDA 机器；Radxa Zero 3W 用来推理，不适合承担 PPO 正式训练。

当前注册表里最值得新手先认识的任务：

| Task ID | 它实际训练什么 | 适合什么时候学 |
|---|---|---|
| `Mjlab-Velocity-Flat-MicroDuck` | 平地速度跟踪和站立 | 第一个任务 |
| `Mjlab-Velocity-Rough-MicroDuck` | 小台阶、网格和缓坡行走 | 平地稳定以后 |
| `Mjlab-VelStand-Flat-MicroDuck` | 行走加跌倒恢复 | 想做统一走/起身策略时 |
| `Mjlab-StandUp-Flat-MicroDuck` | 从坐姿温和站起，并控制身体姿态 | 学单次目标动作 |
| `Mjlab-SitStand-Flat-MicroDuck` | 一个策略在坐姿和站姿间切换 | 学离散命令 |
| `Mjlab-GroundPick-Flat-MicroDuck` | 分阶段低头触地再恢复 | 学周期相位动作 |
| `Mjlab-BallKick-Flat-MicroDuck` | 保持支撑并踢球 | 学物体交互和不对称动作 |
| `Mjlab-Roulade-Flat-MicroDuck` | 前滚、落地、再站稳 | 学动态动作和状态门控 |
| `Mjlab-Spin-Flat-MicroDuck` | 穿轮滑鞋按相位旋转 | 学角速度目标和相位包络 |

带 `-Backlash-` 的任务用于测试串联齿轮间隙；`-Rollers` 和 `Swizzle` 属于轮滑模型。它们不是更高级的“升级版走路”，而是不同物理结构或鲁棒性变体。

### 阶段 1 验收

- `list-envs` 能看到 `Mjlab-Velocity-Flat-MicroDuck`；
- 5 次迭代没有维度、配置、NaN 错误；
- 回放能看到鸭子，能改变速度命令；
- 知道新日志写到 `logs/rsl_rl/<experiment_name>/...`。

---

## 6. 参数在哪里改：按目标查文件

### 6.1 想改站立姿态或零位

文件：`src/mjlab_microduck/robot/microduck_constants.py`

搜索：`HOME_FRAME`

当前关键值包括左右腿镜像的髋、膝、踝，以及颈部和头部。真机侧必须同步核对 `duck-control/src/model.rs` 的 `DEFAULT_POSITION`。两边不一致时，关节位置观测会永久带一个偏差，表现很像舵机不准或策略不稳。

原则：

- 只改仿真 HOME：策略会针对新的零位训练，但旧运行时会错误解释；
- 只改真机 HOME：ONNX 看到的 14 个关节角整体偏移；
- 换舵机花键方向或装配零位后，应先测零位，再同时维护两端；
- 不要用 HOME 去掩盖错误的舵机方向，方向应在总线/模型映射层处理清楚。

### 6.2 想改关节行程、质量、惯量、碰撞或脚底摩擦

文件：

- `robot/microduck/joints_properties.xml`：关节默认属性、限位、原生 PD 备用配置；
- `robot/microduck/robot_walk.xml`：走路模型的 body、geom、mass、inertia、mesh；
- `robot/microduck/robot_groundcontact.xml`：允许身体接地的动作；
- `robot/microduck/config_mjcf_*.json`：Onshape 导出配置；
- `microduck_constants.py`：`soft_joint_pos_limit_factor=0.9`。

注意三种参数不要混淆：

```text
机械关节 limit        = 结构允许到哪里
soft limit factor 0.9 = 训练提前保留安全余量
action scale           = 网络输出换算成多大角度偏移
```

换外形和质量后，应重新导出/计算质量与惯量。只换 STL 视觉网格但保留旧质量，画面会像新机器，动力学仍是旧机器。

### 6.3 想改舵机动力学

文件：`src/mjlab_microduck/robot/microduck_constants.py`

搜索：`_BAM_ACTUATOR_KWARGS`

当前训练配置：

| 参数 | 当前值 | 含义 |
|---|---:|---|
| `motor_name` | `xl330` | 使用 BAM 内置 XL330 参数族 |
| `model` | `m6` | 使用含复杂摩擦项的 M6 模型 |
| `kp_fw` | 200 | 模拟舵机固件位置 P 增益 |
| `vin_range` | 6.5～8.2 V | 每个环境的电池电压 |
| `vin_drop_gain_range` | 0.0～0.2 | 多舵机出力造成的压降 |
| `vin_min` | 6.0 V | 压降后的下限 |
| `delay_min_lag/max_lag` | 3～6 仿真步 | 命令延迟范围 |
| `target_names_expr` | 排除 `passive_*` | 只驱动 14 个主动关节 |

`kp_fw=200` 与 XML 里的 `kp=0.55` 不是同一层，不能直接互换。当前实体由 BAM 接管；XML 中历史原生 PD 参数主要用于无 BAM 对照。

### 6.4 想改走路/跑步目标速度

文件：`tasks/microduck_velocity_env_cfg.py`

搜索：`command.ranges`

当前范围：

```python
lin_vel_x = (-0.4, 0.4)   # 前后 m/s
lin_vel_y = (-0.3, 0.3)   # 横向 m/s
ang_vel_z = (-1.0, 1.0)   # 转向 rad/s
```

`TURN_IN_PLACE_FRACTION=0.15` 会专门抽取原地转向样本。只扩大最大速度并不自动得到“跑步”：策略可能用更快的小碎步、拖脚或倾倒来换速度分。

推荐一次只把前进上限从 `0.4` 提到 `0.5`，保留后退范围不变，观察速度误差、摔倒率、腾空时间和脚高。确认稳定后再到 `0.6`。超过真实执行器能力的命令只会训练出奖励妥协，不会创造额外力矩。

### 6.5 想让脚抬高或步子更明显

同一走路配置中搜索：

- `air_time.weight`：离地时间奖励强度；
- `threshold_min/max`：有效离地时间窗口；
- `foot_clearance.target_height`：摆动脚净空目标；
- `foot_swing_height.target_height`：摆动阶段脚高目标；
- `pose.std_walking`：偏离 HOME 的容许程度；
- `action_rate_l2`：动作变化惩罚。

当前 checkout 的脚高目标均为 `0.02 m`。`air_time.threshold_min` 的上游值是 `0.125 s`，你当前工作区的实验值是 `0.04 s`。后者意图是先奖励任何真实抬脚，等 `Metrics/air_time_mean > 0.10` 后再逐步收紧。

典型因果关系：

| 调整 | 可能得到 | 常见副作用 |
|---|---|---|
| 增大 `air_time.weight` | 更愿意迈步 | 跳步、站立时乱抬脚 |
| 降低 `threshold_min` | 更早获得学习信号 | 小碎步也能得分 |
| 增大 `target_height` | 脚抬得更高 | 耗能、落地冲击、步频下降 |
| 放宽腿部 `std_walking` | 更大动作空间 | 姿态怪、关节撞限位 |
| 强化 `action_rate_l2` | 更平滑 | 太早强化会压死探索 |

### 6.6 想让动作更稳、更平滑

搜索：

- `upright.weight/std`：躯干直立；
- `body_ang_vel.weight`：抑制 roll/pitch 晃动，不惩罚 yaw；
- `angular_momentum.weight`：抑制整体角动量；
- `action_rate_l2`：相邻动作差；
- `joint_torque_rate_l2`：相邻力矩差；
- `cfg.curriculum["action_rate_weight"]`：平滑惩罚何时增强。

走路任务不是一开始就把动作变化惩罚设为 `-1.0`，而是从 `-0.1` 分阶段收紧，到约 1500 次 PPO 迭代达到 `-1.0`。原因是早期需要探索，过早抑制动作会学成“站着最安全”。

### 6.7 想提高 sim-to-real 鲁棒性

走路配置顶部的开关与范围是第一入口：

| 随机项 | 当前状态 | 当前起始范围/设置 |
|---|---|---|
| 躯干质心 | 开 | ±3 mm，课程扩到 ±15 mm |
| 头部组件质心 | 开 | ±3 mm，课程扩到 ±10 mm |
| 质量+惯量 | 开 | 0.95～1.05 倍，一起缩放 |
| BAM 摩擦 | 开 | 0.9～1.1 倍 |
| armature | 开 | 0.9～1.1 倍 |
| 速度冲击 | 开 | 每 3～6 s，±0.3 m/s |
| IMU 安装误差 | 开 | 随机轴最大 6° |
| 编码器偏置 | 开 | ±0.015 rad |
| kP / kD | 关 | 范围存在但目前不生效 |
| 关节 damping | 关 | BAM 下这条路径本来也不是主要入口 |
| 初始机身倾斜 | 关 | pitch ±10°、roll ±5° 仅为预设 |

源码顶部 `COM_RANDOMIZATION_RANGE` 后的旧注释仍写“课程扩到 ±8 mm”，但本版本实际 `com_range` 课程的最后一档是 `0.015 m`，即 ±15 mm。训练行为由课程表决定，本文采用实际执行值；读参数时应检查定义和后续覆盖，不能只读顶部注释。

原则不是“随机越大越好”。DR 应覆盖实测误差，而不是覆盖想象中的最坏情况。随机范围过大时，策略会为了所有虚构机器人都不倒，学成紧张、保守、难以行走的折中动作。

### 6.8 想改传感器噪声和延迟

在走路配置的 `Observations` 段搜索 `Unoise` 和 `delay_*`：

| 观测 | 当前噪声 | 当前延迟 |
|---|---:|---:|
| 躯干角速度 | ±0.03 | 0～1 控制步 |
| 投影重力 | ±0.01 | 0～1 控制步 |
| 关节位置 | ±0.001 rad | 编码器偏置另算 |
| 关节速度 | ±0.25 rad/s | 固定 1 控制步 |

固定 IMU 安装偏角应在运行时标定并纠正；训练中的随机轴 6° 用来增强容忍度，不能代替已知偏差的校准。

### 6.9 想改课程学习节奏

文件还是任务配置，搜索 `cfg.curriculum`。

课程的 `step` 是环境步，不是 PPO 迭代号。当前每次迭代每环境采样 `24` 步，因此：

```text
第 N 次 PPO 迭代对应 step = N × 24
```

课程函数位于 `tasks/mdp.py`，常用入口：

- `reward_weight`：分阶段改奖励权重；
- `standing_envs_curriculum`：增加零速度站立样本；
- `pose_command_range_curriculum`：扩大姿态命令；
- `com_range_curriculum`：扩大质心随机化；
- 各任务自己的 phase、reset mixture 和 disturbance 课程。

不要从 `env.cfg` 临时读写当前课程状态；项目约定由 manager 和事件参数维护。

### 6.10 想改 PPO 网络和训练超参数

每个任务文件最底部都有独立的 `*RlCfg`。走路是 `MicroduckRlCfg`：

| 参数 | 当前值 | 新手建议 |
|---|---:|---|
| actor/critic 隐层 | 512, 256, 128 | 前四个阶段不要改 |
| 激活 | ELU | 不改 |
| observation normalization | 开 | 必须保留并正确导出 |
| PPO clip | 0.2 | 不改 |
| entropy | 0.01 | 探索不足/过强时才研究 |
| epochs / mini-batches | 5 / 4 | 不改 |
| learning rate | 1e-3 adaptive | 不改 |
| gamma / lambda | 0.99 / 0.95 | 不改 |
| desired KL | 0.01 | 不改 |
| rollout steps | 24 | 课程换算依赖它 |
| save interval | 250 | 可按磁盘和观察频率改 |
| max iterations | 50,000 | 是上限，不代表一定要跑满 |

新手最常见误区是行为不好就先调学习率。多数情况下，问题其实在目标不可达、奖励漏洞、重置分布或仿真物理。

---

## 7. 怎样做第一个单变量 A/B 实验

以“鸭子只会贴地碎步”为例。

### 7.1 写下假设

```text
现象：air_time_mean 长期约 0.04 s，air_time reward 近零。
假设：0.125 s 的奖励门槛太高，策略从未收到抬脚正反馈。
只改：threshold_min 0.125 → 0.04。
不改：速度范围、脚高目标、PPO、DR、随机种子策略。
```

### 7.2 每个实验必须记录

复制 `rl-series/experiments/TEMPLATE.md`，至少填：

- git commit 与 `git diff`；
- task ID、环境数、最大迭代、随机种子；
- 唯一变量；
- baseline 和 candidate 的 checkpoint；
- 同一组命令下的回放；
- 结论、是否回滚、下一步。

### 7.3 优先观察的指标

| 指标 | 说明 | 期望趋势 |
|---|---|---|
| episode length | 是否经常早早摔倒 | 上升后稳定 |
| velocity tracking reward/error | 是否真跟上命令 | reward 上升、error 下降 |
| `air_time_mean` | 是否真的迈步 | 脱离零附近，但不是越大越好 |
| foot height/clearance | 是否拖脚 | 接近目标，不持续过冲 |
| upright / tilt | 躯干是否稳定 | 稳定，不靠大幅前倾作弊 |
| action std / entropy | 是否仍在探索 | 逐步下降，不能突然塌缩 |
| penalty reward | 惩罚符号是否正确 | 所有 penalty 贡献应 ≤ 0 |

最后一条非常重要：项目里有两类惩罚函数。基础 cost 常返回正数，需要负权重；名字含 `*_penalty`、`*_l1` 的自取负函数可能返回负数，需要正权重。最可靠的检查不是看名字，而是看日志中每个惩罚贡献是否始终不大于零。

---

## 8. 从走路一步一步做出跑步

当前任务列表没有独立的 Running 环境。`microduck_velocity_env_cfg.py` 虽然给 `std_running` 赋值，但它目前等于 `std_walking`，不能把这理解为已有成熟跑步策略。

### 8.1 第一阶段：先做“走快”而不是“跑”

以 `make_microduck_velocity_env_cfg` 为模板，建立独立任务，保持 61/14 契约和全部 DR/观测设置。

只调整：

1. `lin_vel_x` 正向上限：0.4 → 0.5 m/s；
2. 训练样本增加中高速 bucket，避免均匀采样导致高速样本稀少；
3. 回放固定测 0、0.2、0.4、0.5 m/s；
4. 保持脚高、air time、平滑项不变，先测策略自然反应。

通过标准：0.5 m/s 跟踪误差下降，同时低速和站立能力没有明显退化。

### 8.2 第二阶段：让“跑态”有可辨认的物理定义

跑步不只是速度更大。需要先决定你接受哪一种定义：

- 快速步行：始终至少一只脚接地；
- 跑步：允许短暂双脚离地；
- 跳跃式跑步：有明显腾空和更高冲击。

Microduck 尺寸小、舵机和落地冲击敏感，建议先做快速步行，再谨慎开放短腾空。

可能需要的奖励变化：

- 速度高时提高有效 air-time 窗口，低速时仍保持站立/走路规则；
- 使用速度条件化奖励，不能让零命令环境也通过跳跃刷分；
- 适量提高摆动脚高度；
- 检查支撑脚滑动和落地冲击；
- 平滑和力矩变化惩罚在探索后期逐渐增强。

不要直接删除 `upright` 或大幅减弱动作正则。先在小幅变化中确认机器的可实现上限。

### 8.3 第三阶段：做课程

推荐课程：

```text
0～500 iter     主要训练 0～0.4 m/s，复制已验证步态
500～1200       加入 0.4～0.5 m/s
1200～2500      加入 0.5～0.6 m/s，并加强脚高/离地目标
2500 以后       加强摩擦、电压、推扰动与动作平滑
```

数字只是实验起点，不是已验证的官方跑步配方。是否推进下一阶段，应由速度误差、摔倒率和回放共同决定。

### 8.4 为什么建议单独任务

对新手，先用独立 `microduck_running_env_cfg.py` 更容易解释因果：日志目录独立、速度分布明确、不会破坏已经能走的基线。等走和跑都稳定后，再研究一个由速度命令自动切换步态的统一策略。

---

## 9. 从简单舞蹈一步一步做复杂动作

舞蹈有两条路线。

### 9.1 路线 A：关键帧播放，不用 RL

如果动作完全固定、地面和负载也固定，先用关键帧插值。这是验证机械限位、舵机方向和节拍的最快方法。强化学习只在需要平衡、抗扰、落地或适应误差时增加价值。

### 9.2 路线 B：节拍/相位命令 + RL 平衡

这是推荐路线：人定义舞蹈节奏和目标姿态，RL 学习怎样在真实动力学下跟随目标而不摔倒。

现有项目已有可借用的结构：

- `SitStandCommandCfg`：离散姿态命令；
- `GroundPickPhaseCommandCfg`：用周期相位驱动动作；
- `spin_phase_from_command`、`spin_rate_by_phase`：相位包络；
- `phase_pose_track` / `phase_pose_track_l1`：按相位跟踪目标姿态；
- `microduck_roulade_env_cfg.py`：动态动作的连续进度、落地门控和课程。

### 9.3 第一个舞蹈只做四拍

建议动作：站稳 → 左摆 → 右摆 → 回中，同时轻微点头。

1. 用相位 `φ∈[0,1)` 表示一个周期；
2. 使用 `sin(2πφ), cos(2πφ)` 两个槽表达相位，避免 `0.99→0.00` 的不连续；
3. 定义 4～8 个关键帧，再做平滑插值；
4. 奖励目标关节姿态、直立和双脚接地；
5. 惩罚滑脚、自碰撞、动作突变和过大力矩；
6. 先固定慢节拍，再随机节拍；
7. 最后再加外力和物理随机化。

若要保持现有 61 维接口，可像 ground-pick/spin 一样复用某两个命令槽编码相位，但真机运行时必须用完全相同的编码。不要在仿真里用真实 phase，部署时却只给一个按钮状态。

### 9.4 舞蹈课程建议

```text
阶段 A  固定 6 s 周期，只跟踪腿部小幅摆动
阶段 B  加头部关键帧，保持双脚着地
阶段 C  周期随机到 4～8 s
阶段 D  扩大摆幅，加入踏步
阶段 E  加电压、摩擦、质量和轻微推扰动
阶段 F  随机起始相位，测试中途接管和循环衔接
```

### 9.5 舞蹈的常见奖励漏洞

- 只有姿态奖励：策略可能倒在地上摆关节；
- 只有节拍奖励：策略可能用抖动高频穿过目标；
- 完成奖励每步都发：越早到终点越能持续刷分；
- 相位在 1→0 跳变：观测和目标突然不连续；
- 强制所有关节精确跟踪：没有余量用于保持平衡；
- 一开始就加很强平滑惩罚：策略不敢探索动作。

解决方式是连续相位、状态门控、一次性或限速的成功奖励，以及给平衡修正保留自由度。

---

## 10. 新动作应该复制哪个模板

| 新动作 | 最接近模板 | 原因 |
|---|---|---|
| 走快、跑、横移 | `microduck_velocity_env_cfg.py` | 连续速度命令和成熟步态 DR |
| 蹲下再站起、两种舞姿切换 | `microduck_sitstand_env_cfg.py` | 一个策略处理两种离散状态 |
| 固定起点到固定终点的鞠躬 | `microduck_standup_env_cfg.py` | 单次动作、终点姿态清晰 |
| 踢球 | `microduck_ball_kick_env_cfg.py` | 物体交互、支撑脚与目标速度 |
| 连续旋转 | `microduck_spin_env_cfg.py` | 相位包络和角速度目标 |
| 翻滚、跳起、落地动作 | `microduck_roulade_env_cfg.py` | 连续进度、阶段门控、落地奖励 |
| 轮滑动作 | `microduck_velocity_rollers_env_cfg.py` | 被动轮关节和轮地摩擦 |

新增任务的源码工作流是：

1. 复制最接近的 cfg，而不是从空文件写；
2. 在文件顶部集中放 `ENABLE_*` 和行为常量；
3. 保留 61 维观测、14 维动作、BAM 和 NaN 防护；
4. 只留下与动作目标不冲突的基础奖励；
5. 在 `tasks/mdp.py` 添加必要的纯函数和有状态门控；
6. 在 `tasks/__init__.py` 注册新的 task ID；
7. 给新任务单独的 `experiment_name`；
8. 在 `tests/` 添加配置和函数测试；
9. 64 环境 × 5 迭代冒烟；
10. 回放确认物理和奖励，再跑正式训练。

对不对称动作，例如只踢右脚、只向右旋转，默认不要启用左右镜像 symmetry。对称动作也应先关闭，行为稳定后再做有对照的开启实验。

---

## 11. 换成其他厂家舵机：完整参数传播链

其他厂家和类型当然可以用来学习和调试，但分两种目标：

- 学控制/GPIO/PWM：SG90、串口舵机都可以，适合单舵机练习；
- 复刻整只 Microduck：必须同时满足重量、尺寸、力矩、速度、回差、协议、供电和散热，不能只看堵转力矩。

换舵机应按四层处理。

### 11.1 机械层

记录：尺寸、重量、安装孔、输出轴、舵盘、可用角度、零位方向。

要影响：

- CAD/打印件舵机仓；
- MJCF mesh 和关节 axis/position；
- 各 body 的 mass、inertia、CoM；
- 关节 range 和碰撞几何；
- HOME/真机默认姿态。

### 11.2 电气层

记录：额定/允许电压、空载/堵转电流、线序、总线电平、温度保护。

要影响：

- 电池和降压方案；
- BAM 的 `vin_range`、`vin_min`、压降范围；
- 真机电压保护和温度阈值；
- 动作峰值、电流预算和同时启动策略。

### 11.3 通信层

当前 `duck-control/src/bus.rs` 明确使用 `rustypot::servo::dynamixel::xl330::Xl330Controller`，协议 V2、1 Mbps，并读取 XL330 的寄存器地址。换成飞特等协议时，不能只改型号字符串。

推荐保留上层 `RobotIo`：

```text
RobotIo::read()         → positions / velocities / currents / IMU
RobotIo::write()        → 15 个位置目标
RobotIo::set_gain()     → 全关节增益
RobotIo::set_torque()   → 扭矩开关
RobotIo::slow_sensors() → 电压与每舵机温度
```

为新协议写一个新的后端，实现同样的单位和顺序。需要逐项解决：

- sync read/write 是否支持；
- 位置、速度、电流的原始单位换算；
- 方向和零点；
- ID 与广播规则；
- 寄存器地址、返回延迟、超时；
- IMU 板是否还能与舵机共用一条总线。

若新舵机协议无法与当前 Dynamixel IMU 板共总线，就要分总线或改 `imu_to_dxl` 固件。这是系统结构变化，不是一个配置项。

### 11.4 动力学层：先辨识一只，再买齐

当前 BAM 参数库有 XL330 和若干其他型号，但没有本项目计划使用的 HL-1910 参数。正确路径是实测拟合一个自定义 JSON。

台架至少记录：

- 多个电压；
- 多个固件 P 增益；
- 空载和带已知臂长/负载；
- 正向与反向；
- 慢速摩擦、阶跃、正弦和抬落轨迹；
- 温度从冷机到热机的变化；
- 指令到运动的延迟；
- 正反向趋近同一点的回差。

BAM 仓库给出的流程是：

```bash
# 1. 用对应厂家的 record 模块采集原始日志
uv run python -m bam.<manufacturer>.all_record \
  --port <串口> --motor <型号> \
  --mass <负载kg> --arm-mass <摆臂kg> --length <臂长m> \
  --vin <电压> --logdir data_raw

# 2. 重采样/清洗为 5 ms 时间步
uv run python -m bam.process --raw data_raw --logdir data_processed --dt 0.005

# 3. 拟合；建议 m1～m6 都做并留一个 kP 作验证集
uv run python -m bam.fit \
  --actuator <型号名> --model m6 \
  --logdir data_processed --validation_kp <留出的kP> \
  --output params/<型号名>/m6.json

# 4. 对比实测与仿真
uv run python -m bam.plot \
  --actuator <型号名> --logdir data_processed --sim \
  --params params/<型号名>/m6.json
```

若 BAM 没有该厂家的采集模块，要先照已有 manufacturer 包增加协议读写和轨迹记录器。不要拿另一款舵机的 JSON 改个文件名。

### 11.5 把自定义舵机模型接到 Microduck

固定版本的 `BamActuatorCfg` 支持 `json_path`。未来修改训练配置时，概念上从：

```python
motor_name="xl330",
model="m6",
```

换成：

```python
json_path="/绝对路径/params/hl1910/m6.json",
```

`json_path` 与 `motor_name + model` 二选一，不能同时填写。其余这些仍需按实测决定：

- `kp_fw`：新舵机真实运行增益；
- `vin_range` / `vin_min`：真实供电窗口；
- `vin_drop_gain_range`：电池、线束和总电流造成的压降；
- `delay_min_lag/max_lag`：实测端到端延迟；
- BAM friction DR：多只舵机、冷热状态的离散度；
- backlash 变体：实测总死区，不是厂商宣传值。

### 11.6 为什么换舵机后要重训

策略学到的是“给出一个关节偏移后，这台具体机器会怎样动”。速度、摩擦、延迟、回差和电压响应一变，同一动作会产生不同的落脚时间和姿态。旧 ONNX 可以用作仿真退化基线，但不能默认直接上新硬件。

推荐顺序：走路 flat → 站立/恢复 → 坐站 → 其他技能 → rough/backlash。没有必要第一天重训全部策略。

---

## 12. 仿真参数、运行时参数必须成套记录

运行时 `deploy/robotd.toml` 的关键默认/说明值：

| 参数 | 当前值/默认 | 用途 |
|---|---:|---|
| `bus.port` | `/dev/ttyS2` | Radxa 舵机/IMU 总线 |
| `control.hz` | 50 Hz | 必须与训练时间尺度一致 |
| `policy.action_scale` | walk 0.9 | 原始动作 → 关节偏移 |
| `policy.standing_action_scale` | 1.0 | 站立策略动作尺度 |
| `policy.gain` | 200 | 真机位置 P 增益 |
| `standing_gain_ratio` | 0.8 | 站立相对增益 |
| `head_lowpass` | 0.5 | 头部目标低通默认 |
| `legs_lowpass` | 0.7 | 腿部目标低通默认 |
| `voltage_adapt` | false | 可选电压动作补偿 |
| `deadman_ms` | 500 ms | 命令失联后停止速度 |
| `gain_limp` | 50 | 摔倒软化增益 |
| `battery_empty_shutdown` | true | 低电自动坐下/关机 |

### 12.1 当前低通配置存在版本冲突

这是不能省略的事实：

- 当前训练仓 `AGENTS.md` 说策略训练时不加动作低通，除非训练和运行时成套验证；
- 当前运行时配置仍默认头部 `0.5`、腿部 `0.7`，并称这些是 alpha 策略训练时的值；
- 当前 `microduck_velocity_env_cfg.py` 中没有对应的 `ACTION_LOW_PASS_*` 实现。

因此不能笼统写“必须开”或“必须关”。正确做法是把以下三件东西视为一个版本集合：

```text
训练 commit + checkpoint/ONNX + runtime 动作处理配置
```

对自己新训练的策略，先在 CPU 部署预演和吊装真机上做四组 A/B：无低通、仅头部、仅腿部、0.5/0.7；记录速度误差、相位延迟、跌倒、峰值电流和抖动，再锁定配置。

---

## 13. 训练、导出和部署的质量门

### 13.1 每次配置改动

```bash
uv run --with pytest pytest tests/
CUDA_VISIBLE_DEVICES="" uv run train <TASK_ID> \
  --env.scene.num-envs 64 \
  --agent.max_iterations 5
```

检查：task 能创建、61/14 不变、奖励均为有限值、无 NaN、课程键名存在。

### 13.2 正式训练

```bash
uv run train <TASK_ID> --env.scene.num-envs 4096
```

简单单次动作通常先预留约 1000 次迭代看能否发现；步态和恢复通常需要 4000～6000 甚至更多。`max_iterations` 是停止上限，不能代替收敛判断。

### 13.3 回放

```bash
uv run play <TASK_ID> \
  --checkpoint-file <model_N.pt> \
  --viewer viser --num-envs 1
```

不要只挑最好看的命令。固定测试矩阵至少包括：零命令、低速、最高训练速度、转向、命令突变、不同随机种子、低电压、摩擦上下界。

### 13.4 正式导出

```bash
uv run scripts/export.py <TASK_ID> \
  --checkpoint-file <model_N.pt> \
  --onnx-file <out.onnx> \
  --viewer viser
```

必须走项目导出脚本，因为 actor 开启了 observation normalization，导出脚本会把归一化器烘进 ONNX。手工只导网络时，仿真 play 可能正常，真机却会收到未归一化输入。

### 13.5 CPU 部署预演

```bash
uv run scripts/infer_policy.py --walking <out.onnx>
```

它用 50 Hz 控制、BAM 执行器复演部署路径。还应分别测试 `--no-bam`、电压、增益、延迟和 action scale 参数，确认模型不是只在单一设定下碰巧工作。

### 13.6 真机测试金字塔

```text
L1 单舵机台架
L2 15 舵机总线但不装负载
L3 整机悬空、低增益、人工急停
L4 吊装带少量负载
L5 软垫地面、零命令站立
L6 低速直行和停止
L7 转向、最大训练速度
L8 单次技能和连续动作
```

任何一级出现方向错误、撞限位、过流、过热、通信丢包或异常振荡，都回到前一级，不靠安全代码硬扛。

---

## 14. 出现问题时先查哪里

| 现象 | 优先检查 | 不要先做什么 |
|---|---|---|
| 训练完全不动 | 目标是否可达、正奖励是否有梯度、平滑惩罚是否过强 | 调大学习率 |
| 站着刷分不走 | 速度奖励/命令采样、高速样本占比、奖励门控 | 再加强站立奖励 |
| 只贴地碎步 | air time 门槛、脚高、摆动奖励是否能收到 | 同时改所有步态项 |
| 越训越抖 | action/torque rate 课程、奖励 jackpot、观测延迟 | 只在部署端加很重滤波 |
| 仿真很好，真机摔 | HOME、关节顺序、方向、动作尺度、BAM、电压、时延、低通 | 继续训练更多迭代 |
| 一换电池状态就变 | `vin_range`、压降、运行时电压补偿 | 固定成满电仿真 |
| 个别舵机总跑偏 | 零点、方向、编码器偏置、回差、ID 映射 | 放大整体 DR 掩盖坏舵机 |
| 动作撞限位 | XML range、soft limit、HOME、action scale | 只靠真机裁剪 |
| reward 数值很好但动作怪 | 奖励漏洞、重复发成功奖、缺少状态门控 | 相信总 reward 一个数 |
| 导出后才坏 | ONNX 是否含 normalizer、输入 61/输出 14 | 手写 checkpoint 转 ONNX |

---

## 15. 推荐的新手七次实验

每次只改一个变量，并保留 baseline。

1. 原配置 64 环境 × 5 iter：学会启动和找日志；
2. 原配置 64 环境 × 100 iter：看 reward、entropy 和 episode length；
3. 固定 checkpoint 回放多组速度：学会行为评估；
4. A/B 一个 `air_time.threshold_min`：学会从现象提出假设；
5. A/B 一个前进速度上限：理解命令分布与能力边界；
6. 建立“走快”独立任务：学会复制模板、注册和写测试；
7. 建立四拍左右摇摆任务：学会相位、姿态跟踪和稳定门控。

完成第 7 项以后，再开始 HL-1910 单舵机辨识。这样你已经知道拟合出的电压、延迟、摩擦和回差最终会进入哪里，不会把台架实验做成一堆无法用于训练的数据。

---

## 16. 一页参数索引

| 我想改…… | 文件 | 搜索词 |
|---|---|---|
| 初始站姿/零位 | `robot/microduck_constants.py` | `HOME_FRAME` |
| 真机零位与 ID | `duck-control/src/model.rs` | `DEFAULT_POSITION`, `JOINT_IDS` |
| 舵机模型 | `robot/microduck_constants.py` | `_BAM_ACTUATOR_KWARGS` |
| 自定义舵机 JSON | 同上 | `json_path`（替代 `motor_name/model`） |
| 关节限位/原生 PD | `robot/microduck/joints_properties.xml` | `range`, `chosen_actuator` |
| 质量、惯量、几何 | `robot/microduck/robot_*.xml` | `mass`, `inertia`, `geom` |
| 走路速度 | `tasks/microduck_velocity_env_cfg.py` | `command.ranges` |
| 抬脚 | 同上 | `air_time`, `foot_clearance`, `foot_swing_height` |
| 稳定和平滑 | 同上 | `upright`, `action_rate_l2`, `angular_momentum` |
| DR 开关与范围 | 同上顶部和 Events 段 | `ENABLE_`, `RANDOMIZATION_RANGE` |
| 传感器噪声 | 同上 Observations 段 | `Unoise`, `delay_min_lag` |
| 课程 | 同上末段 | `cfg.curriculum` |
| PPO | 任务文件最底部 | `*RlCfg` |
| 奖励/事件实现 | `tasks/mdp.py` | 函数名 |
| 新任务注册 | `tasks/__init__.py` | `register_mjlab_task` |
| 真机协议 | `duck-control/src/bus.rs` | `Xl330Controller`, `RobotIo` |
| 61/14 布局 | `duck-control/src/obs.rs` | `OBS_LEN`, `ACTION_LEN` |
| 真机动作尺度/低通 | `deploy/robotd.toml` | `action_scale`, `lowpass`, `gain` |
| 真机安全 | 同上 | `[safety]` |

常用搜索命令：

```bash
rg -n 'HOME_FRAME|_BAM_ACTUATOR_KWARGS' src/mjlab_microduck/robot
rg -n 'command.ranges|cfg.rewards|cfg.curriculum' src/mjlab_microduck/tasks
rg -n 'OBS_LEN|ACTION_LEN|DEFAULT_POSITION|JOINT_IDS' /Volumes/dev/dev/microduck/duck-control/src
rg -n 'action_scale|lowpass|gain|deadman' /Volumes/dev/dev/microduck/deploy/robotd.toml
git diff -- src/mjlab_microduck/tasks
```

---

## 17. 最重要的五条原则

1. 先复现，再改动；一次只改一个变量。
2. 先验证物理目标可达，再开始长训练。
3. 奖励好看不等于动作正确，曲线、状态指标和回放缺一不可。
4. 训练 commit、ONNX 和运行时处理必须作为同一个版本集合。
5. 换舵机先测一只，真机先吊装；任何安全保护都不能替代逐级验证。

配套阅读：

- [30 天强化学习计划](../rl-series/30天计划.md)
- [换舵机重训全流程](换舵机重训全流程.md)
- [执行器选型与参数](执行器选型.md)
- [硬件入门](硬件入门.md)
- [硬件方案逆向](硬件方案逆向.md)

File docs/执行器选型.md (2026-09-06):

# 执行器选型与参数

> 🔌 舵机总线的协议对照（含飞特 STS/SCS 与 HD-1910 规格）见 [硬件方案逆向](硬件方案逆向.md)。

**简体中文** · [English](actuator-selection.en.md)

## 电机：Dynamixel XL330，整机 15 个

| | |
|---|---|
| 型号 | **Dynamixel XL330-M288-T**（证据见下） |
| 数量 | **15 个**（`xl330` 网格在整机 MJCF 中被引用 15 次） |
| 受控 | **14 个**进策略动作空间：左腿 5 + 颈头 4 + 右腿 5 |
| 第 15 个 | 驱动喙 / 下颚，走 `passive_*` 连杆，**不进动作空间** |
| 安装 | M2 螺丝（本体 Ø2.0×4 过孔 + Ø1.6×8 攻丝孔） |
| 供电 | ⚠️ **舵机额定 3.7–6.0 V，实际总线 6.6–8.2 V —— 超压运行**，见下节 |

## ⚠️ 电压真相：XL330 被超压运行

> **勘误（2026-09-04）**：本文此前把 XL330 写成「标称 7.4V 级舵机」。**这是错的**，
> 而且它连带影响了下面对飞特 STS3032 的否决理由和力矩对比结论。

**Robotis 官方规格**（[XL330-M288-T e-manual](https://emanual.robotis.com/docs/en/dxl/x/xl330-m288/)，2026-09-04 核）：

| 项目 | 官方值 |
|---|---|
| 输入电压 | **3.7 – 6.0 V** |
| 推荐电压 | **5.0 V** |
| 堵转力矩 | 0.42 N·m @3.7 V ／ **0.52 N·m @5.0 V** ／ 0.60 N·m @6.0 V |
| 减速比 | 288.4 : 1 |
| 尺寸 / 重量 | 20 × 34 × 26 mm ／ 18 g |

**而 Microduck 实际给舵机的电压是 6.6 – 8.2 V**，三处源码互相印证：

| 来源 | 值 |
|---|---|
| `microduck_constants.py` 的 BAM 配置 | `vin_range=(6.5, 8.2)`、`vin_min=6.0` |
| `robotd` 电压自适应 | 钳位 **6.0 – 9.5 V** |
| 电池 | NP-F550 为 2S 锂电，标称 7.4 V，满电 8.4 V |

#### 直接证据：官方 HAT 原理图

有人会问「XL330 不是 5 V 输入吗，哪来的超压」。5 V 是 **ROBOTIS 数据手册的推荐值**，
不是 Microduck 的实际接法。官方 HAT 是开源的（`pollen-robotics/elec_RPI_Robot_HAT`，
Apache-2.0），原理图第 4/6 页 `dynamixel.kicad_sch` 写得很清楚：

| 电路 | 实际连接 |
|---|---|
| 三个 Dynamixel 接口 J11 / J13 / J14 | 电源脚接 **`+BATT`**（电池原电压），图上标注 `3A max`，串 TH1 100R 热敏保护 |
| `+BATT` 到舵机之间 | **没有任何降压** —— J13/J14 经 TH1 100R 热敏、J3/J11 直连。<br>（U10 LM5050-1 理想二极管在 buck **之后**的 `+5V` 那一路，不是电池输入端） |
| 板上唯一的降压 | **U9 AP63205** + **L4 6.8 µH**（Fsw 1.1 MHz，2 A）→ 输出 `+5V` |
| `+5V` 去哪 | **树莓派 40 针排针 J4**、音频功放 PAM8406D、EEPROM —— 原理图旁边就附着树莓派功耗表（Pi 5: 9–10 W／Pi 4B: 6–7.6 W／Pi Zero 2W: 1.5 W） |

**整张 HAT BOM（47 行）里只有一颗 buck、一个电感。** 没有第二路降压。
也就是说 5 V 那一路是**给树莓派的**，舵机直接挂在电池上 —— 2 A 的 AP63205
本来也带不动 15 个 XL330（单个堵转就约 1.5 A）。

**结论：Pollen 让 XL330 长期工作在其额定上限（6.0 V）之上，最高约 8.2 V。**

### 这意味着什么

- ✅ **力矩比官方标称更大** —— 堵转力矩随电压近似线性上升，8 V 下会明显高于 0.52 N·m。
  这大概是他们敢用 18 g 舵机扛 800 g 整机的原因之一。
- ⚠️ **寿命与发热是代价** —— 超压运行对绕组和 MOSFET 都是额外负担。官方从未公开
  这方面的数据，**以下为推断**：这可能与社区反馈的舵机发热、以及官方开始考虑
  卖维修包有关（见 [社区动态](社区动态.md)）。
- ⚠️ **复刻时你要自己做这个决定**。照抄 = 同样超压；想稳妥就加一级降压到 5–6 V，
  代价是力矩下降，**可能需要重训策略**（官方 ONNX 是在超压条件下训出来的）。

> 这也解释了为什么固件里有「电压自适应」：`scale × (7.4 / 实测EMA)`。
> 电池从 8.4 V 掉到 6.5 V 的过程中，同样的 PWM 输出的力矩差很多，
> 不做补偿的话策略在电量不同时表现会飘。

---

## 关节行程

| 关节 | 行程 | 弧度 |
|---|---|---|
| `hip_yaw` | -25° ~ +30° | -0.436 ~ 0.524 |
| `hip_roll` | ±22° | ±0.384 |
| `hip_pitch` / `knee` / `ankle` / `head_pitch` | ±90° | ±1.571 |
| `neck_pitch` | -90° ~ +60° | -1.571 ~ 1.047 |
| `head_yaw` | ±170° | ±2.967 |
| `head_roll` | ±25° | ±0.436 |

> 右腿 `hip_yaw` 是左腿的镜像：-30° ~ +25°。

## BAM M6 执行器配置（当前使用）

来自 `robot/microduck_constants.py`：

```python
_BAM_ACTUATOR_KWARGS = dict(
    motor_name="xl330",
    model="m6",
    target_names_expr=(r"^(?!passive_).*",),   # 排除被动关节
    kp_fw=200.0,             # 固件位置环刚度（microduck 保留 200，microban 用 125）
    vin_range=(6.5, 8.2),    # 每个环境启动时采样的电池电压
    vin_drop_gain_range=(0.0, 0.2),   # 负载压降 V_drop = gain * sum(|tau|)
    vin_min=6.0,             # 压降后的电压硬下限
    delay_min_lag=3,         # 指令延迟（控制步）
    delay_max_lag=6,
)
```

BAM M6 是**电压级**模型：不是简单 PD，而是模拟固件 PD → PWM → 电压 → 电流 → 力矩的完整链路，
再叠加负载相关的摩擦（库仑 + Stribeck + 载荷项）。这是 sim2real 的核心。

### 三个关键的域随机化

| 项目 | 范围 | 物理含义 |
|---|---|---|
| `vin_range` | 6.5 – 8.2 V | 电池从满电到亏电的全过程 |
| `vin_drop_gain_range` | 0.0 – 0.2 | **负载压降** —— 多个舵机同时出力时母线电压跌落 |
| `delay_min/max_lag` | 3 – 6 步 | 指令到执行的通信+固件延迟 |

`actuator/friction_dr_bam.py` 额外加了 **per-env `friction_scale`**，
只缩放**与速度无关**的摩擦预算（静摩擦 / 齿轮箱），黏性项保持标称 ——
因为静摩擦才是 sim2real 不确定性的主要来源。

### 齿轮回差建模

`BacklashEncoderBamActuator` 复现了一个真实但容易被忽略的细节：

> 真实舵机的磁编码器装在齿轮间隙的**输出侧**，所以固件位置环闭环在
> `主关节角 + 回差角` 上。舵机在死区里空转时，**测到的位置不变，PD 误差也不变**。

实现上把 `cmd.pos` 改成 `qpos[main] + qpos[backlash]`。
速度 `cmd.vel` 故意保持电机侧 —— 它驱动反电动势和摩擦，那是转子物理量，不是编码器信号。

回差模型见 `robot_allcollisions_backlash.xml`，每个舵机串一个
`passive_<joint>_backlash` 被动铰链。

## 五组标定过的 MuJoCo 原生 PD 参数（备用）

`joints_properties.xml` 里留了 5 组，都是 BAM 实测标定的结果。
**如果你不用 BAM 而用 MuJoCo 内置 PD，直接抄这些数**：

| class | damping | frictionloss | armature | kp | forcerange (N·m) |
|---|---|---|---|---|---|
| `chosen_actuator` ⭐ | 0.053 | 0.0048 | 0.0018 | 0.55 | ±0.96 |
| `chosen_actuator_antoine` | 0.044 | 0.013 | 0.0017 | 0.43 | ±0.75 |
| `chosen_actuator_old` | 0.048 | 0.006 | 0.002 | 0.52 | ±0.91 |
| `chosen_actuator_new` | 0.041 | 0.032 | 0.002 | 0.386 | ±0.67 |
| `perfect_actuator` | 0.15 | 0.1 | 0.001 | 10.0 | ±20.0 |

⭐ = 当前默认（注释标注 "marc"）。`ctrlrange` 统一 ±10.0。
`perfect_actuator` 是理想电机，仅用于对照，**不要拿它训练要上真机的策略**。

被动关节：`passive_wheel` / `passive_joint` —— damping 0，frictionloss 0，armature 0.0001。

## 为什么是 XL330：一切都由重量预算决定

XL330 不是因为「力气大」被选中的，是因为**在 18 g 里塞下了一整套东西**：

```
电机 + 288:1 减速箱 + 编码器 + 驱动器 + 位置环 + 总线接口  =  18 g
```

整机才 737 g，15 个舵机就占 270 g（37%）。这个盒子里放不下别的方案。

### 力矩从哪来：减速箱，不是电机

### 型号是怎么定下来的

官方从未在任何公开材料里点过具体子型号 —— 源码里只有 `motor_name="xl330"`，**没有后缀**。
但有一条独立证据链可以定到 **M288-T**：

1. `microduck_rl` 的仿真用 **BAM** 执行器模型，配置是
   `motor_name="xl330"`, `model="m6"`（`microduck_constants.py`），
   加载 `bam/params/xl330/m6.json`
2. BAM 出自 [`Rhoban/bam`](https://github.com/Rhoban/bam)，其 README 的
   「**已辨识模型库**」列表里，这颗舵机的条目写的是
   **`Dynamixel XL330-M288-T`**
3. 也就是说，**训练策略所依据的摩擦模型，是在一颗实物 XL330-M288-T 上台架辨识出来的**

旁证：2026-09-03，韩国机器人行业观察者 [@Allyakutaku](https://x.com/Allyakutaku/status/2095331280233926948)
称从官方视频中辨认出的电机型号为 XL330-M288-T。

> ⚠️ 严格说，上述证据直接证明的是**仿真标定所用的舵机**是 M288-T。
> 实物用同型号是极强推断，但**不是 Pollen 的官方声明**。

型号里的 **288 就是减速比 288.35:1**（同系列还有 M077，77.9:1）。

里面那颗空心杯电机本身只能出几个 **毫**牛·米，靠 288:1 放大到
MJCF 里标定的 **±0.96 N·m**（约 9.8 kg·cm）。

**代价直接写在模型里**：减速比越大回差越明显 —— 所以 `robot_allcollisions_backlash.xml`
给每个关节串了 `passive_*_backlash` 被动铰链，建模 **±1.0°** 的齿轮间隙。

---

## 为什么不能用闭环步进

这是个常见的想法，在**静态定位**场景（CNC、3D 打印机）确实合理，
但足式机器人上有几条硬伤：

### 1. 重量 —— 直接判死刑

| | 单个重量 | 含什么 |
|---|---|---|
| **XL330** | **18 g** | 电机 + 减速箱 + 编码器 + 驱动器 + 控制环 + 总线，**全在里面** |
| NEMA 8 步进 | ~60 g | **裸电机**，不含编码器、驱动器、减速箱 |

15 个裸 NEMA 8 就 900 g —— **光电机超过整机总重（737 g）**，还没算外围。

### 2. 保持功耗

步进保持位置**必须持续通额定电流**。双足站立时 15 个关节都要持续出力矩，
而电池只有 2600 mAh 2S、续航约 1 小时。

舵机是位置闭环，**误差小、负载轻时电流接近零**。站着几乎不耗电。

顺带还有热：15 个步进在 25 cm 密闭塑料壳里持续通额定电流，散不掉。

### 3. ⭐ 反驱性 —— 最关键，也最容易被忽略

足式机器人**必须能吸收冲击**。看官方 `robotd.toml` 里的 `limp_fall`：

> 检测到要摔倒时，**把增益从 200 降到 `gain_limp = 50`**，
> 让关节「顺着外力走而不是跟地板较劲」，软着陆之后再用 600 ms 拉回站姿。

**步进做不到这件事。** 它只有两个状态 —— 通电锁死、断电自由转（断电还有齿槽力矩），
**中间没有可调阻抗**。

闭环步进能纠正丢步，但那是**事后恢复**，不是**实时柔顺**。
落脚冲击的瞬间需要的是顺从，不是一次纠偏瞬态。

整套 sim2real 配方（BAM 模型、`kp_fw=200`、增益梯度、软着陆）建立在
**「舵机是一个刚度可调的弹簧」** 这个前提上。步进不是弹簧，是位置锁。

### 4. 布线

15 个舵机 = **一条 3 线菊花链**。
15 个步进 = 15×4 相线 + 15 根编码器线 + 15 个驱动板。
在 25 cm 的身体里、脖子还要转 —— 塞不进去。

### 5. 市面上没有这个规格

18 g、288:1 减速箱、集成编码器与驱动器、总线菊花链 —— **这个东西不存在**。

---

## 换成飞特 STS3215 会怎样

STS3215（深圳飞特）单价约 **¥60–70**，是 XL330（约 ¥299）的**五分之一**，
而且 **力矩还更大**（1.86 N·m vs 0.96 N·m）。看起来是显然的降本方案。

**但它重 3 倍（约 55–60 g vs 18 g）。** 下面是实测后果。

### 硬数据：同架构、换舵机，整机质量变化

两边都是 15 个刚体的双足机器鸭，MJCF 里的质量总和：

| | 舵机 | **整机质量** | 身高 |
|---|---|---|---|
| **Microduck** | XL330 | **737.2 g** | 25 cm |
| **Open Duck Mini v2** | STS3215 | **2107.1 g** | 42 cm |

**2.86 倍。**

> 💡 **Open Duck Mini v2 就是「STS3215 版的答案」。**
> 同一个工程师（Antoine Pirrone，Pollen R&D）、同样的双足鸭架构 ——
> 换了舵机之后，整台机器人只能做成 42 cm、2.1 kg。

### 执行器参数：每一项都差一个数量级

| 参数 | XL330 (`chosen_actuator`) | STS3215 (`sts3215`) | 差距 |
|---|---|---|---|
| **kp** | 0.55 | **17.8** | **32×** |
| **forcerange** | ±0.96 N·m | **±3.35 N·m** | **3.5×** |
| **damping** | 0.053 | **0.60** | **11×** |
| **frictionloss** | 0.0048 | **0.052** | **11×** |
| **armature** | 0.0018 | **0.028** | **15.5×** |
| 回差建模 | **±1.0°** | ±0.5° | — |

> 数据来源：`microduck_rl/.../joints_properties.xml` 与
> `Open_Duck_Playground/playground/open_duck_mini_v2/xmls/joints_properties.xml`
>
> 📌 反直觉的一点：**XL330 建模的回差反而更大**（±1° vs ±0.5°）。
> 可能是两个项目的建模口径不同，也可能是 288:1 高减速比的代价。

**这不是微调，是两种完全不同的执行器。**

### 不改机械件能换吗：不能

| 约束 | 说明 |
|---|---|
| **尺寸** | XL330 实测外形 **29 × 20 × 34 mm**（量自 `xl330.stl`）。机械件的舵机腔按此挖出，STS3215 是明显更大的一档，塞不进去 |
| **安装接口** | 舵机盘螺孔分度圆、输出轴规格、外壳固定孔位全不同 —— 本仓库反推的那套 M2 孔位（Ø2.2 过孔 + Ø4.4 沉孔）是照 XL330 的 |
| **质量预算** | 15 × (57−18) ≈ **多出 585 g**，还不算为承重而加粗的结构件。737 g 的机器人加 585 g，重心、关节力矩需求、结构强度全部推倒 |

**这不是「换个舵机」，是「换一台机器人」。**

### 会失效的 / 能保留的

| 失效 | 保留 |
|---|---|
| ❌ 官方 9 个 ONNX 策略 | ✅ **61 维观测契约 + 14 维动作** |
| ❌ BAM M6 标定（给 XL330 做的辨识） | ✅ 训练框架（microduck_rl / Playground） |
| ❌ 上文 5 组 `chosen_actuator` 参数 | ✅ sim2real 方法论（BAM 辨识、域随机化、回差建模） |
| ❌ 回差模型（要重测） | |
| ❌ MJCF 质量惯量（全部重算） | |
| ❌ 通信协议（飞特 SCS/STS，非 Dynamixel V2） | |

> **通信这条有个好消息**：Open Duck Mini 用的是 `rustypot.feetech(port, 1000000)` ——
> **同一个 `rustypot` 库，只是换协议模块**，波特率同样 1 Mbps。
> 所以 Rust 运行时里换掉 `Xl330Controller` 是可行的，不必重写通信层。

**要改的是「机器人模型」和「执行器模型」，不是算法本身。**

---

## 同级别舵机横向对比：那个空档为什么还没被填上

「有没有更便宜的 XL330」是最常被问的问题。答案是：**同重量级的确实存在，
但没有一个能同时满足力矩和电压。**

| 型号 | 重量 | 尺寸 (mm) | 堵转力矩 | 电压 | 编码器 | 减速比 |
|---|---|---|---|---|---|---|
| **Dynamixel XL330-M288-T** ⭐ | **18 g** | **20 × 34 × 26** | **0.52 N·m @5 V**<br>0.60 @6 V / 0.42 @3.7 V | **3.7–6.0 V**<br>推荐 5 V | 12-bit | 288.4:1 |
| **飞特 STS3032** | 20 g | **23.2 × 12.1 × 28.5** | 0.44 N·m<br>(4.5 kg·cm @6V) | **4.8–6 V** | 12-bit | — |
| **飞特 SCS0009** | **11 g** | — | 0.23 N·m<br>(2.3 kg·cm) | 6 V | 10-bit | 1:416 金属齿轮 |
| 飞特 STS3215 | ~55–60 g | 大一档 | 1.86 N·m<br>(19 kg·cm) | 7.4 V | 12-bit | — |
| Dynamixel XL330-M077 | 18 g | 同 M288 | 低（高速版） | 同 M288 | 12-bit | 77.9:1 |
| **宇树 S288** ⭐ | **19.5 g** | **34 × 20 × 23** | **存疑（见下）** | **12.6 V** | **15-bit 双编码器<br>+ 输出端编码器** | **288.35:1** |
| 宇树 J288 | 35 g | 34 × 20 × 23 | 存疑（金属齿轮版） | 25.2 V | 同 S288 | 288.35:1 |

> **本表统一用厂商标称堵转力矩**（2026-09-04 核自各家官网），可以横向比。
>
> 本仓库 MJCF 里那个 `forcerange = ±0.96` 是 **MuJoCo 的仿真力限，不是厂商值**，
> 已从本表移出 —— 此前版本拿它和别家的堵转值并排比较，是错的。
>
> XL330 尺寸以 Robotis 官方 20×34×26 mm 为准；量自 `xl330.stl` 的 29×20×34
> 包含舵盘和线座，比本体大。
> 尺寸量自 `xl330.stl`。
> 其余为厂商公开规格。**价格因地区差异极大，此处不列** ——
> 同一颗 STS3032 在印度进口零售约 ₹3,451，在国内是完全不同的价位。

### ⭐ 宇树 S288：唯一一个全面对标 XL330 的产品

2026 年出现的新选项。**机械参数几乎逐项对上 XL330**，连型号里的 "288" 都一样：

| | XL330-M288 | 宇树 S288 | |
|---|---|---|---|
| 重量 | 18 g | **19.5 g** | ✅ |
| 尺寸 | 20 × 34 × 26 mm | **34 × 20 × 23 mm** | ✅ |
| **减速比** | **288.35:1** | **288.35:1** | ✅ **完全相同** |
| 固定螺丝 | M2 | **M2** | ✅ |
| 总线物理层 | 单线半双工 TTL | **单线半双工 TTL (1-Wire)** | ✅ |
| 波特率 | 1 Mbps | **6 Mbps** | ⬆️ 6× |
| 电机 | 有刷空心杯 | **无刷 FOC** | ⬆️ |
| 编码器 | 12-bit，转子侧 | **15-bit 双编码器 + 输出端编码器** | ⬆️⬆️ |
| 控制方式 | 位置环 + kp | **力矩前馈 + 可调刚度/阻尼** | ⬆️⬆️ |
| **电压** | ~7.4 V (2S) | **12.6 V (3S)** | ⚠️ **不兼容** |
| **总线容量** | 253 个地址 | **15 个（0~14，15 为广播）** | ⚠️ |
| 力矩 | **0.96 N·m** | **存疑** | ⚠️ |

> S288 的尺寸、接口、协议与控制方式均取自官方
> [《无刷数字舵机 J288/S288 使用手册》](https://www.unitree.com/images/%E6%97%A0%E5%88%B7%E6%95%B0%E5%AD%97%E8%88%B5%E6%9C%BAJ288S288%E4%BD%BF%E7%94%A8%E6%89%8B%E5%86%8C.pdf)（11 页，已通读）；
> 重量、电压、编码器位数取自[官网产品页](https://www.unitree.com/cn/DigitalServo/)。

#### 两个实质升级

**1. 阻抗控制，不是位置伺服**

手册给出的混合控制律：

```
τ = τ_ff + k_p × (p_des − p) + k_d × (ω_des − ω)
```

**力矩前馈 + 可调刚度 + 可调阻尼**，底层是 FOC 闭环。

Microduck 的 `limp_fall` 靠把 kp 从 200 降到 50 换取柔顺 —— 用 S288 可以**直接给力矩前馈**，
比调增益干净得多，而且这正是足式机器人真正需要的关节力控。

**2. 有输出端编码器 —— 直接消灭回差问题**

返回数据结构里有 `uint16_t OutPos : 13`（输出端传感器，2^13 表示 1 圈）。

XL330 的编码器在**转子侧**，齿轮间隙测不到 —— 所以 `microduck_rl` 才必须
建 `passive_*_backlash` 被动铰链，还要在仿真里复现「固件位置环透过回差读数」
这个细节（见上文 `BacklashEncoderBamActuator`）。

**S288 直接测真实关节角，这一整套复杂度可以省掉。**

反馈还包括壳体温度、绕组温度、舵机端电压、转子扭矩/速度/位置，以及 22 位故障码
（过流、过压、欠压、芯片/MOS/壳体/绕组过热、三路编码器错误……）。比 XL330 丰富得多。

#### 三个硬约束

**① 电压 12.6 V vs 7.4 V**
Microduck 是 2S（NP-F550），S288 要 **3S**。电池、供电、HAT 全要重做。

**② 总线只能挂 15 个舵机**
地址空间 **0~14**（15 为广播）。Microduck 正好 15 个舵机 —— **刚好用满**，
但它总线上还挂着 **IMU 板（ID 200）**。
**S288 方案下 IMU 必须另走 SPI/I2C。**

> 这与本仓库在 [硬件方案逆向](硬件方案逆向.md) 中给出的建议一致：
> 把 IMU 从舵机总线挪到主控 SPI，可靠性反而更好。

**③ ⚠️ 力矩数据存疑 —— 这是决定性参数，尚未解决**

官网标 S288 堵转扭矩「同向 **0.07 N·m** / 反向 **0.2 N·m**」，但手册明确写：

> 「协议中的所有参数均为**转子端**数据，减速比为 288.35，
> 若需将转子数据换算为输出端数据，则需乘以或除以该减速比。」

两种解读都说不通：

| 解读 | 输出端力矩 | 判断 |
|---|---|---|
| 那两个数是**转子端** | 20 / 58 N·m | ❌ 19.5 g 的舵机不可能 |
| 那两个数是**输出端** | 0.2 N·m | ❌ 只有 XL330（0.96）的 1/5，不构成平替 |

**必须向宇树确认或实测。** 建议问清楚这四点：

1. 「堵转扭矩」标的是**转子端**还是**输出端**？
2. 「同向 / 反向」具体指什么（正反转？还是驱动 / 反驱？）
3. **输出端**的额定持续力矩和峰值力矩各是多少？
4. 12.6 V 是额定还是上限？能否降压到 7.4 V 使用（力矩会掉多少）？

> 旁证推测：J288 是 35 g 金属齿轮版，标 0.5 / 1.5 N·m。若 1.5 为输出端，
> 对 35 g 无刷 + 288:1 是合理的，还强过 XL330。按比例外推 S288 输出端可能在
> 0.5 N·m 上下 —— **但这只是推测，不可据此决策。**

#### 结论：机械像平替，电气和协议不是

| | |
|---|---|
| ✅ **机械** | 尺寸、重量、减速比、M2 孔位高度对应，机械件可能不用大改 |
| ⚠️ **电气** | 12.6 V vs 7.4 V，电池和供电系统要重做 |
| ❌ **协议** | 宇树自定义 20 字节命令 / 26 字节返回 + CRC32 @ 6 Mbps，与 Dynamixel Protocol V2 完全不同；`rustypot` 不支持，通信层要重写 |
| ❌ **策略** | 官方 9 个 ONNX 作废 —— 力矩特性与控制模式都变了 |
| ✅ **换来的** | 关节力控、输出端编码器、6 Mbps 总线、丰富的温度与故障反馈 |

**如果力矩问题能确认过关，这是目前唯一值得认真评估的 XL330 替代方案。**

### STS3032：尺寸合格，力矩和电压不合格

这是最接近的候选：**比 XL330 还小**（23.2×12.1×28.5 vs 29×20×34），
重量几乎一样（20 g vs 18 g），12-bit 编码器同级，半双工总线同架构。

**但两个问题 —— 注意，此前本文对这两条的判断都过重了：**

1. **力矩约为 85%，不是 46%** —— 同电压口径下 0.44 N·m @6 V vs XL330 0.52 N·m @5 V。
   此前写的 46% 是拿 0.44 去比仿真力限 0.96，两个量不可比。
2. **电压上限 6 V —— 但 XL330 的上限同样是 6 V。**
   区别不在舵机规格，而在 **Pollen 选择了超压运行**（见上节）。
   要照搬 STS3032，要么同样超压（风险自负），要么加一级降压到 5 V。

### 能不能混搭

| 关节组 | 数量 | 力矩需求 | STS3032 够不够 |
|---|---|---|---|
| 腿（髋 yaw/roll/pitch、膝、踝） | 10 | 高 —— 要支撑 737 g 整机并吸收落地冲击 | ❌ **不够** |
| 颈 / 头（pitch、yaw、roll） | 4 | 中 —— 驱动 189 g 头部总成 | ⚠️ 可能够 |
| 嘴 | 1 | 低 | ✅ 够 |

**混搭在理论上可行，全换不行。** 但混搭要解决 7.4 V → 6 V 的降压，
而且两种舵机的 BAM 参数、回差、响应延迟都不同 —— 训练时要按关节分组建模，
复杂度上升不少。

### 一个旁证：Pollen 自己就在用飞特

**SCS0009 用在 Pollen 的 [Amazing Hand](https://github.com/pollen-robotics/AmazingHand)
和 HopeJR 上。**

说明他们**不是不知道便宜方案，是 Microduck 的腿真的需要那个力矩** ——
手指关节 0.23 N·m 够用，双足机器人的膝盖不够。

### 空档在哪

```
需求：18–20 g · ≥0.5 N·m @额定 · 能耐 2S 直供或自带降压 · 总线菊花链 · 集成编码器与驱动器
现状：Robotis XL330 全部满足，但需超压到 6.6–8.2 V 使用
      宇树 S288  重量/尺寸/减速比/总线均满足，额定 12.6 V (3S) 是唯一障碍
      飞特 STS3032 重量/尺寸满足，力矩约 85%，与 XL330 同为 6 V 上限
```

**空档正在被挤压 —— 宇树 S288 已经补上了大半。** 卡住的是电压等级（3S vs 2S）
和尚未澄清的力矩标注。若宇树出一个 2S 版本、或力矩确认达到 0.9 N·m 级别，
这个位置就被填上了。

飞特的产品线正在往这个方向走 —— **SCS0009（11 g）→ STS3032（20 g）
是一条明确的「小型化 + 总线化」路径**，壳子已经做到位了，
缺的是把减速比或电压等级提上去、把力矩做到 0.9 N·m 级别。

叠加两个市场信号：

- **LeRobot 生态**（Hugging Face）已把 STS3215 推成机械臂的事实标准
- **Microduck 发布 7 小时销售额破百万美元**，证明了 18–20 g 级别的真实需求

> ⚠️ **这是趋势判断，不是预测。** 截至 2026-08-31 没有任何厂商新品公告。
> 但空档明确、壳子现成、需求被验证 —— 这个位置被补上是有可能的。

**如果真出现了**，本仓库的价值反而放大：机械几何、装配关系、电控方案、
执行器参数都已摸清，做适配是几天的事，而不是从零开始。

---

## 结论：没有中间路线

| 路线 | 结果 |
|---|---|
| **保 XL330** | 机械件可直接用本仓库导出的 CAD，官方策略直接跑。舵机成本约 **¥4500** |
| **换 STS3215** | 舵机成本降到约 **¥1000**，但机械件全部重做 + 策略全部重训 —— **实际上就是去做 [Open Duck Mini v2](https://github.com/apirrone/Open_Duck_Mini)**（它全套开源：BOM、Onshape CAD、36 个 STL、装配指南、现成走路策略） |
| **换宇树 S288** | 机械几乎对得上（19.5 g / 34×20×23 / 288.35:1 / M2），且带来关节力控与输出端编码器。但要换 3S 电池、重写通信层、重训策略，**且力矩标注存疑必须先确认** —— 见上文专节 |
| **等** | 空档正在被挤压。若出现 2S 版本或力矩确认达标，本仓库的机械与电控资料可直接复用 |

**同重量级里，力矩够的只有 Robotis 一家。** 飞特 STS3032 尺寸更小、重量相当，
但力矩约为 **85%**（0.44 N·m @6 V vs XL330 0.52 N·m @5 V，同电压口径）且电压上限 6 V；SCS0009 更轻（11 g）但只有 0.23 N·m。
详见上一节的横向对比。

## 成本提醒

Dynamixel XL330-M288-T 的渠道差价极大（2026-09-04 实查）：ROBOTIS 国际站 **$23.90**、
美国站 **$27.49**、Generation Robots 含税 **€40.20**、MyBotShop **€41.95**。
15 个合计 **$359 / $412 / €603 / €629**；
国内价约 ¥299/个，15 个约 **¥4500** —— 均已超过整机 **$399** 售价。
$399 是规模化价格，个人零散采购拿不到。

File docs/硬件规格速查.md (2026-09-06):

# Microduck 硬件规格速查

> 📘 新手先看 [硬件入门](硬件入门.md)（一块板一块板讲）；完整推导见 [硬件方案逆向](硬件方案逆向.md)。

> 一页纸版本。完整推导过程和证据见 [硬件方案逆向.md](硬件方案逆向.md)。
> 所有数据来自 `pollen-robotics/microduck` 的源码、设备树和配置文件 —— **代码即规格书**。

**一句话**：Radxa Zero 3W（RK3566）跑 Armbian + 一条 1 Mbps TTL 串口总线挂 15 个
Dynamixel XL330 + 两块自制板。

---

## 系统框图

```
                ┌──────────────────────────────┐
                │   Radxa Zero 3W (RK3566)     │  65 × 30 mm
                │   Armbian · 内核 6.1.115      │  Pi Zero 形态
                └──┬────────┬─────────┬────────┘
      /dev/ttyS2   │        │ 40-pin  │ MIPI CSI
      1 Mbps TTL   │        │  I2C3   │
    ┌──────────────┘        │ 400kHz  └── IMX219 摄像头（转 90°）
    │                       │
    │              ┌────────▼─────────────────┐
    │              │  Pollen RPI Robot HAT    │  65×30mm 自制板(已开源)
    │              │   ├ TLV320AIC3104  0x18  │  音频 codec
    │              │   ├ BMI088   0x19/0x68   │  焊了但没用
    │              │   └ Stemma J5 → ToF 0x29 │  VL53L5CX/L8CX
    │              │  电池经此板供电            │
    │              └──────────────────────────┘
    │
════╪══════════ Dynamixel 总线 · Protocol V2 · 1 Mbps ══════════
    │
    ├── 15 × XL330   ID 左腿20-24 / 颈头嘴30-34 / 右腿10-14
    └── imu_to_dxl v2 板   ID 200   ← LSM6DSV16X
```

**核心设计**：一条总线搞定一切。IMU 不走 I2C，做成 Dynamixel 从机挂在舵机总线上，
和 15 个舵机在**同一次 `sync_read`** 里读出。电池电压也不用电量计，
直接读舵机报告的自身供电电压。

---

## 主控

| 项目 | 值 |
|---|---|
| 模块 | **Radxa Zero 3W** —— 市售模块，**不是定制载板** |
| SoC | **RK3566**（4× Cortex-A55 + Mali-G52 + NPU） |
| 尺寸 | 65 × 30 mm，Pi Zero 形态，40 针树莓派兼容排针 |
| 系统 | **Armbian**（Debian 系），vendor 内核 6.1.115 |
| 策略推理 | ONNX Runtime ≥1.23（装 1.28.0），`dlopen` 加载 |
| NPU 推理 | rknn-toolkit2 —— **Armbian 默认关闭**，需刷 overlay 并重启 |

> 依据：设备树 `compatible = "radxa,zero-3w", "rockchip,rk3566"`；
> 全仓库 "radxa" 出现 182 次。

### 为什么传闻说是树莓派

1. 自制板名字**就叫 "RPI Robot HAT"**
2. Pi Zero 形态 + 40 针树莓派兼容排针
3. 摄像头是**树莓派 Camera v2**（IMX219）
4. **原型阶段确实用的树莓派 Zero 2W** —— `robotd.toml` 注释：50 Hz 控制环
   *"is inherited from the prototype, where it was chosen on a Raspberry Pi Zero 2W"*

前身 Open Duck Mini v2 **至今仍用树莓派 Zero 2W**，因为它不做视觉和 WebRTC 推流。

### 为什么必须 Linux SoC 而非 MCU

要同时跑：ONNX 策略推理 @50Hz、720p30 H.264 硬件编码 + WebRTC 推流、
NPU 目标检测、GStreamer 拥塞控制（占 7.6% 一个核）、蓝牙手柄 + 手机 App + WiFi。
**STM32 / ESP32 做不了。**

---
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

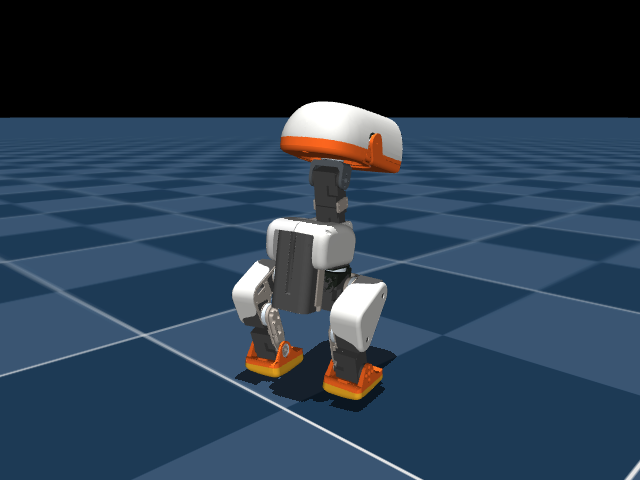
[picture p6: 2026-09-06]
rl-series/assets/回放-A-100迭代-关键帧3.png

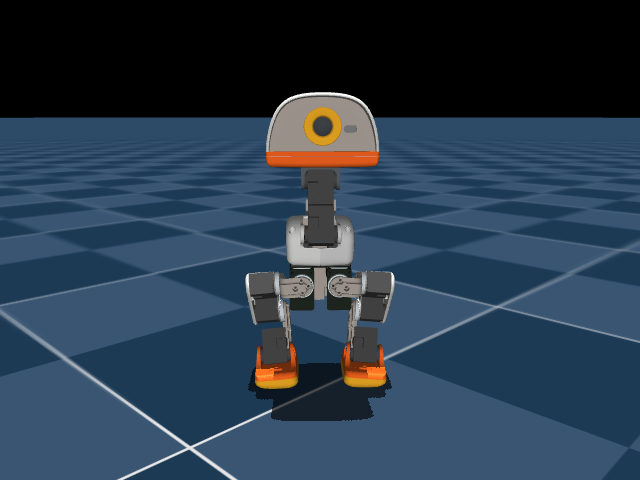
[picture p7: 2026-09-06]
rl-series/assets/回放-C-2199迭代-关键帧1.png

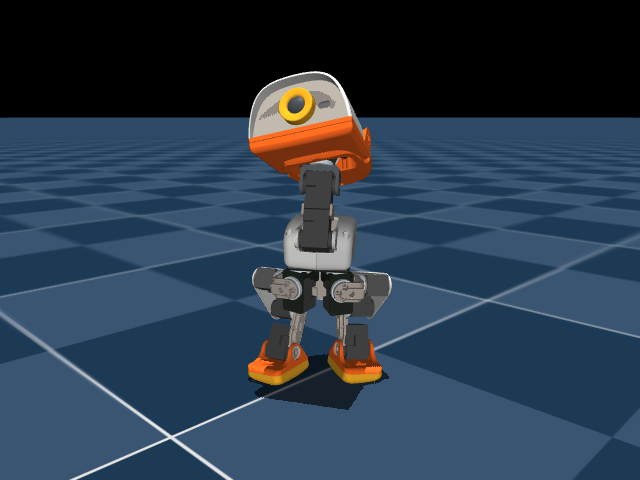
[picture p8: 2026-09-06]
rl-series/assets/回放-C-2199迭代-关键帧2.png

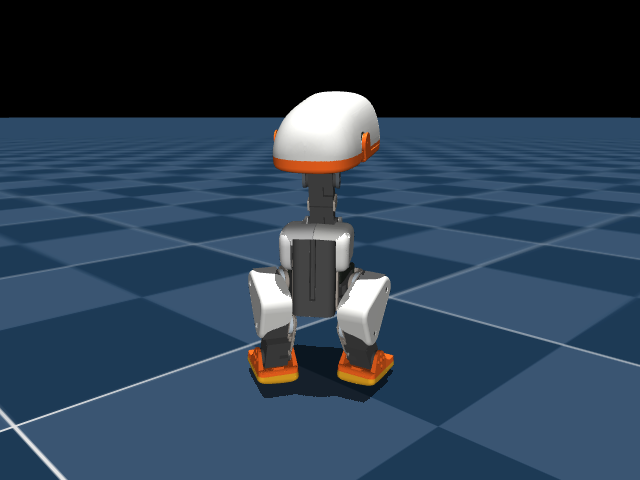
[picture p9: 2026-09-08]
rl-series/assets/回放-面板-expC-cpu2000-model_2198-关键帧4.png

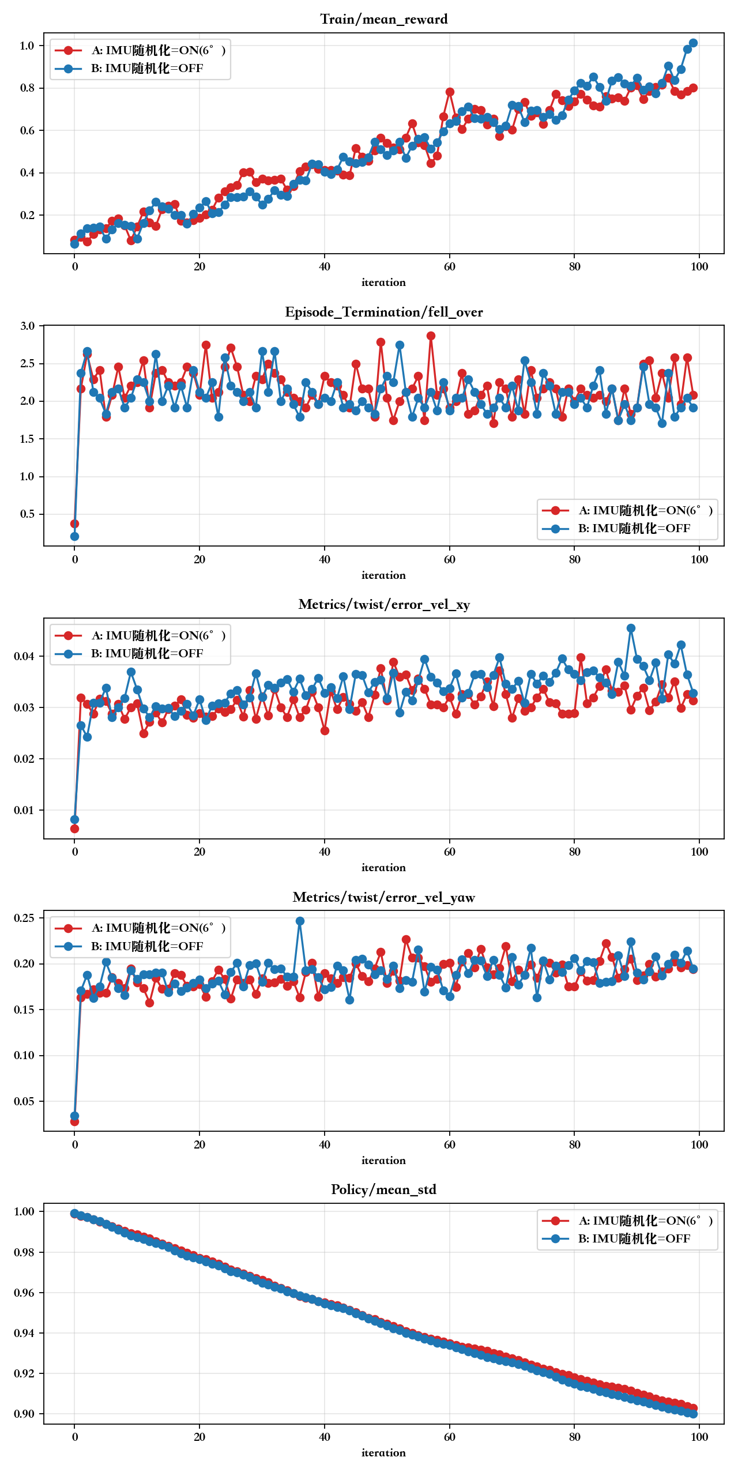
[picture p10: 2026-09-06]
rl-series/assets/exp001-AB对比.png

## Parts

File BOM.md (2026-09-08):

# 整机物料清单（BOM）

**简体中文** · [English](BOM.en.md)

复刻一台 Microduck 需要的全部东西。数量取自上游 `robot_walk.xml` 的 geom 引用计数
（**38 种网格 / 75 个实例**），不是估的。

> ⚠️ **官方从未公布过 BOM。** 这份清单是从公开的 MJCF、STL、Rust 源码和 KiCad 工程反推的。
> 每一项都标了依据。价格随地区和时间变化很大，**只作量级参考**。
>
> 核对日期：**2026-09-04**。⚠️ **上游基线待核**：本仓库 `print/` 下的 STL 与本地
> `microduck_rl` 工作副本逐字节相同，而该副本是 depth-1 浅克隆、HEAD = **`d424a0c`（2026-08-27）**。
> 此前记录的基线 `29e887e` / 重导出 `8dfc08f` 在本地对象库中不存在，**因此"重导出前后 geom
> 计数相同"这句无法验证**。下文所有计数均出自 `d424a0c`。

---

## 一、成本速览

| 类别 | 数量 | 量级 |
|---|---|---|
| **舵机** | 15 | **$359 – €629**（见下，地区差极大） |
| 主控与传感器 | 4 类 | 约 $80 – 120 |
| 电池与供电 | 2 件 | 约 $30 – 50 |
| 轴承 | 14 | 约 $15 – 30 |
| 紧固件 | 约 325 件 | 约 $15 – 25 |
| **PCB 打样（2 块）** | 2 | 约 $60 – 150（含 SMT） |
| 打印耗材 | — | 约 $15 – 30 |

**舵机占绝对大头**，而且渠道差价巨大：ROBOTIS 国际站 $23.90 × 15 ≈ **$359**（低于整机售价），
美国站 $27.49 × 15 ≈ **$412**（约等于售价），欧洲含税则要 **€603–629**（远超）。

> $399 是矽递规模化量产 + 官方供应链的价格，**个人复刻不可能达到**。

---

## 二、舵机（成本核心）

| 型号 | 数量 | 依据 |
|---|---|---|
| **Dynamixel XL330-M288-T** | **15** | `robot_walk.xml` 中 `xl330` 网格引用 15 次 |

- 14 个进策略动作空间，**第 15 个是嘴**（`JOINT_NAMES[9] = "mouth"`，`MOUTH_INDEX = 9`），
  不进策略动作空间（所有 alpha 策略都是 61 维观测 / 14 维动作）。
  ⚠️ **MJCF 里根本没有这个关节** —— `robot_walk.xml` 只有 14 个 hinge joint / 14 个 actuator，
  嘴在所有 MJCF 里都是刚性并进 `jaw_soft` body；`passive_*` default class 在步行模型里零引用
- ID 分配：左腿 20–24 ／ 颈头嘴 30–34 ／ 右腿 10–14
- ⚠️ **型号是推断**：源码只有 `motor_name="xl330"` 无后缀。M288-T 的依据见
  [执行器选型](docs/执行器选型.md#型号是怎么定下来的)

**价格参考**（2026-09-04）：

| 渠道 | 单价 | 15 个 |
|---|---|---|
| Robotis 美国官网 | **$27.49** | **$412** |
| Generation Robots（欧，不含税） | €33.50 | €503 |
| Generation Robots（欧，含税） | €40.20 | €603 |
| MyBotShop | €41.95 | €629 |

> ⚠️ **超压运行警告**：XL330 额定 3.7–6.0 V，而 Microduck 给它 6.6–8.2 V。
> 官方 HAT 原理图里 Dynamixel 接口直接接 `+BATT`（电池原电压），板上唯一的 5 V 降压是给树莓派的。
> 这是官方的选择，不是笔误。详见 [电压真相](docs/执行器选型.md#-电压真相xl330-被超压运行)。

> 🛒 **国内采购淘宝实链**：[电控采购清单](docs/电控采购清单.md)（主控/摄像头/ToF/电源/PCB/线材）、
> [机械采购清单](docs/机械采购清单.md)（轴承/紧固件/热熔螺母/螺纹胶/耗材）。

---

## 三、电子件

| 部件 | 型号 | 数量 | 依据 / 备注 |
|---|---|---|---|
| 主控 | **Radxa Zero 3W** | 1 | 设备树 `compatible = "radxa,zero-3w"`。⚠️ 有多档 RAM/eMMC。官方 2026-08-27 发布页公布 **1 GB / 32 GB**，但 `microduck/` 源码中无佐证（源码本来就不体现板卡 SKU）；**复刻建议 2G/16G**，推算见 [电控采购清单](docs/电控采购清单.md#该买哪个配置)；系统镜像必须带 Rockchip 厂商内核（Armbian 系），否则 NPU 不存在 |
| 摄像头 | 树莓派 Camera v2（**IMX219**） | 1 | `setup-board.sh` 用 `radxa-zero3-rpi-camera-v2` overlay。⚠️ **装歪了四分之一圈，要软件补偿**：当前代码 `mediad/src/main.rs:82` 的 `--rotate` 默认 **90**，注释原文「the head camera is mounted **a quarter turn off**, and this is the one place that fact is written down」。`media-bringup.md:472` 的 180° 是 **alpha 机**数据。**以代码为准 = 90°** |
| 深度 | **VL53L8CX** 或 VL53L5CX 模块 | 1 | 固件两款都支持，按 revision ID 自动识别；地址 `0x29` 或 `0x52`；Stemma/Qwiic 接口 |
| 电池 | **索尼 NP-F550**（2S，7.4 V） | 1 | ⚠️ 见下方勘误 |
| 电池卡座 | NP-F 系列通用卡座 | 1 | 上游只有打印件 `power_support`，**没有触点模型** —— 取电方案需自行解决 |
| 喇叭 | 小型扬声器 | 1 | `speaker` 网格 ×1；HAT 上有 PAM8406 功放和 Wago 端子 |

### ⚠️ 电池型号勘误：是 NP-F550，不是 F970

上游网格文件名叫 `np_f970`，**但这是误导**：

| | |
|---|---|
| 网格实测包围盒 | **70.8 × 38.6 × 20.6 mm** ← 这是 **NP-F550/F570** 的尺寸 |
| 真 NP-F970 | 厚约 **60 mm**、重约 300 g |
| 源码中出现的型号 | **只有 NP-F550**（`model.rs`、`robotd-design.md`），全库搜不到 F970 |

**买 F970 会装不进去，而且 300 g 会吃掉整机 800 g 预算的三分之一以上。**
本仓库此前多处写「NP-F970」，已统一更正。

---

## 四、电路板（2 块，都要自己送厂）

### 板 1：RPI Robot HAT —— 官方已开源，下载即打样

| | |
|---|---|
| 来源 | [`pollen-robotics/elec_RPI_Robot_HAT`](https://github.com/pollen-robotics/elec_RPI_Robot_HAT)（Apache-2.0） |
| 生产文件 | `production/`：Gerber、BOM、贴片坐标、原理图 PDF、STEP |
| **层数** | **4 层**（`F.Cu / In1.Cu / In2.Cu / B.Cu`） |
| **板厚** | **1.0 mm**（KiCad `(thickness 1)`。STL 量出的 0.84 mm 是仿真网格近似值，下单以 KiCad 为准） |
| 尺寸 | **65.0 × 30.9 mm**（KiCad `Edge.Cuts` 实测，圆角 R3.5）。比 Pi Zero 宽 0.9 mm |

> ⚠️ **别拿 STL 或它转出的 STEP 做机械配合。** 仿真网格实测 **65.025 × 30.025 × 0.840 mm**，
> 与真板框差 **宽 0.875 mm、厚 0.16 mm** —— 宽度这一项在 30 mm 的边上是 3%，做卡槽、支柱、
> 开孔会对不上。**机械配合一律按 65.0 × 30.9 × 1.0 走，板框以 Gerber 的 `Edge_Cuts` 层为准。**
> STL/STEP 只适合做 3D 干涉检查与大致定位。
>
> （对照：`pcb__raspberry_pi_zero_2_w` 那个网格是 65.000 × 30.000 × 1.600 mm，是标准 Pi Zero 尺寸，倒是准的 —— 但它只是占位块，实机用 Radxa Zero 3W。）
| BOM | 47 行 / **123 颗元件**，其中 **5 行 DNP 不贴** |
| 贴片位 | `POS.csv` **117 行**，含 3 个基准点 FID1–3 和 H3 → **实际元件 113 个** |
| 手焊可行性 | ❌ **不可能** —— 含 VQFN-32 codec 和 LGA-16 IMU，必须选 SMT 服务 |

**关键器件**（可用于估价与替代）：

| 位号 | 器件 | 作用 |
|---|---|---|
| U2 | TLV320AIC3104IRHBR | 音频 codec（I²C `0x18`） |
| U1 | PAM8406D | D 类功放 |
| MK1 | MEMS 麦克风（LCSC **C7587901**） | 板载。⚠️ 官方 BOM 的 Value 只写 `Microphone_MEMS`，原理图旁只有「Onboard Mic.」，**未给具体型号**；本仓库此前写的 LMA2718 无出处，已撤回 |
| U11 | BMI088 | IMU —— **贴了但软件不用**（即所谓「第二颗 IMU」） |
| U8 | SIT3088E | RS-485 收发器 |
| U10 | LM5050-1 | 理想二极管 OR-ing ＋ 关机检测。⚠️ 位于 buck 之后的 `+5V` 路，非电池输入端防反接 |
| U9 | AP63205 | 降压 |
| U4 | CAT24C32 | EEPROM —— **DNP 不贴**，所以这不是自识别 HAT |
| J13/J14 | JST EH 3P | Dynamixel **TTL** |
| J3/J11 | JST EH 4P | Dynamixel **RS-485** |
| J5–J8 | JST SH 1mm 4P | Qwiic / Stemma（接 ToF） |

⚠️ **打样前必读**：

1. **这块板没有充电电路，也没有 USB-C 输入**。仓库里的 `pwr_supply_charge.kicad_sch`
   是**孤儿图纸**（`main.kicad_sch` 没挂它，标题栏还写着别的项目名）。电池要用外部充电器充。
2. **打开 KiCad 工程需要先装 [`lib_KiCAD`](https://github.com/pollen-robotics/lib_KiCAD)**，
   否则一片未解析符号。只打样则不需要，直接用 Gerber。

### 板 2：`imu_to_dxl` —— 全网无公开工程，必须自己画

| | |
|---|---|
| 状态 | 🔧 **本仓库正在重建**，见 [硬件方案逆向 §三](docs/硬件方案逆向.md) |
| 功能 | 把 IMU 伪装成一个 Dynamixel 从机（ID **200**）挂在舵机总线上 |

**参考 BOM**（本仓库设计，非官方）：

| 位号 | 器件 | 立创编号 | 说明 |
|---|---|---|---|
| U1 | **STM32G031F8P6** | `C529334` | MCU，TSSOP-20。⚠️ **这是本仓库的选型建议，不是逆向所得** —— 官方那块板的 MCU 型号无从还原（见 [硬件方案逆向](docs/硬件方案逆向.md#那-imu_to_dxl-板上是什么-mcu)）。选 F8（64 KB Flash）而非 F6（32 KB）是为双协议固件留余量。<br>**选 ST 的理由不是"生态好"，是两个具体特性**：① 和 IMU 同厂，[`lsm6dsv16x-pid`](https://github.com/STMicroelectronics/lsm6dsv16x-pid) 驱动与 [`lsm6dsv16x_sensor_fusion.c`](https://github.com/STMicroelectronics/STMems_Standard_C_drivers/blob/master/lsm6dsv16x_STdC/examples/lsm6dsv16x_sensor_fusion.c) SFLP 例程现成 —— SFLP 初始化要配 FIFO、融合率、量程，顺序错了不出数；② STM32G0 的 USART 有**硬件 DE（Driver Enable）**，半双工方向自动切换，1 Mbps 下一个 bit 才 1 µs，软件切的抖动就在这个量级 |
| U2 | **LSM6DSV16XTR** | `C5267406` | 六轴 IMU + SFLP 硬件融合，LGA-14 |
| U3 | **SN74LVC2G241DCUR** | `C10430` | 三态缓冲，做单线半双工 |
| U4 | **HT7533-1** | `C14289` | 3.3V LDO，**耐压 30 V**（基础库免上料费） |
| J1/J2 | B3B-EH-A(LF)(SN) | `C160259` | Dynamixel 3P，**2.5 mm**，**与官方 HAT 同料号**，线束通用 |
| **J4/J5** | **B3B-PH-K-S(LF)(SN)** | 待定 | **飞特 3P，2.0 mm 立式**（2026-09-08 新增）。飞特 `AMP2.0-3P` 与 JST EH **间距不同、插不进对方**，所以两套座子并存，用哪种舵机插哪一组。<br>⚠️ **脚序与 J1/J2 完全相反**：`1=DXL_BUS / 2=VDD_BUS / 3=GND`，见 [接线表](hardware/imu_to_dxl/imu_to_dxl-接线表.md)。<br>⚠️ **料号待定** —— 飞特规格书只给了线端型号，板端没给。焊盘阵是三孔 2.0 mm 间距，与其它 2.0 mm 系列通用，换系列只改封装不动焊盘。<br>本体高约 **6.0 mm**，比 EH 立式的 8 mm 更适合 6.65 mm 的躯干内腔 |
| **J3** | **PZ254V-11-06P**（6P，2.54 mm） | `C492405` | **SWD + 串口 printf 合一**。脚序 `1=GND 2=SWDCLK 3=SWDIO 4=UART_TX 5=UART_RX 6=+3V3` —— 前 4 脚不变，原来的 4 针 SWD 排线插 1–4 仍可用。<br>UART 来自 U1 脚 16/17（`PA11[PA9]`/`PA12[PA10]`），经 `SYSCFG_CFGR1` 重映射成 **PA9 = `USART1_TX` / PA10 = `USART1_RX`**（DS12992 Rev 3, Table 12 脚注 4）。<br>**不上 USB**：G031 没有 USB 外设（手册全文零命中，Development support 只有 SWD），加 USB 要多一颗 CH340/CP2102，45×22 mm 板上不划算。调试走 SWD + RTT（`probe-rs` 支持 CMSIS-DAP 上跑 RTT，不停 CPU）；要普通 printf 就插 4/5 脚。<br>⚠️ Cortex-M0+ **没有 SWO/ITM**，别指望 SWO printf |
| C1–C4, C8 | **100 nF 0603** 50 V | `C14663` | 去耦（同官方 HAT 料号）。C1/C2 贴 U2 的 8/5 脚，C3 贴 U3 的 8 脚，C4 贴 U1 的 4 脚 |
| **C5** | **4.7 µF / 16 V / 0603 / X5R**<br>Samsung `CL10A475KO8NNNC` | `C19666` | **MCU 本地储能**，与 C4 一起构成 ST 要求的 `100 nF + 4.7 µF`。<br>依据 **DS12992 Rev 3, Figure 13「Power supply scheme」(p.44)**：`VDD/VDDA` 一路明确标注 `1 x 100 nF + 1 x 4.7 μF`，并 Caution 要求"尽可能贴近引脚，或放在 PCB 背面正对该脚"。<br>立创**基础库**。<br>⚠️ 本表此前把 C5 也写成 100 nF —— 两颗相同的 100 nF 并联只是容量翻倍，频响曲线不变、低频段仍然是空的，不符合手册 |
| **C6** | **10 µF / 25 V / 0805 / X5R**<br>Samsung `CL21A106KAYNNNE` | `C15850` | **LDO 输入**，直接挂 8.4 V 总线。立创**基础库**（免上料费）。<br>⚠️ 8.4 V 直流偏压下 X5R 衰减约 30–40%，实际约 6–7 µF —— 对 LDO 输入够用 |
| C7 | 10 µF 0603 10 V | `C19702` | LDO 输出（3.3 V），10 V 够用 |
| **R1/R2/R4/R5/R7** | **10 kΩ 0603** | `C25804` | 五个上拉，全部接到 3.3 V：<br>**R1 = SPI_CS**（必须）—— 上电与复位期间 PA4 是高阻，CS 浮着可能被 IMU 误判成 I²C 模式<br>**R2 = NRST** —— 芯片内部已有 ~40 kΩ 弱上拉，外面再加一个提高抗干扰<br>**R4 = DE**（必须，2026-09-06 补）—— `1OE#` 低电平使能发送。复位期间 PA1 高阻，这脚若浮成低电平，发送缓冲就打开，本板会往总线上灌数据、和 15 个舵机全撞车。此前只在 CS 上加了上拉、DE 上漏了，由社区评审指出<br>**R5 = DXL_DATA**（2026-09-06 补）—— 总线空闲时无人驱动，`2A` 这个 CMOS 输入浮着会有穿透电流，UART 也可能把噪声当起始位。本板应当自己定义空闲电平，不依赖主机<br>**R7 = RX_EN**（2026-09-07 补）—— `2OE` 原本硬接 3.3 V（接收常开）。改成经 R7 上拉、同时引一根线到 `U1.1 (PB7/PB8)`：默认行为完全不变，但固件多了一个「发送时关掉接收、免去回显」的选项。MCU 复位期间 PB7 高阻，靠 R7 保证 `2OE` 为高 |
| **R6** | **150 Ω 0603** | `C22808` | **数据线源端串阻**（2026-09-06 补）。与 D2 一起构成 HAT 同款的数据线保护：限制短路电流、软化边沿降 EMI。<br>1 Mbps 下 150 Ω 与总线电容构成的延迟约占比特时间的 3%，可接受。<br>依据：官方 HAT `dynamixel.kicad_sch` 用的是 `R33 150R + TH1 100R` 串联共 250 Ω |
| **D2** | **BZT52C5V1-7-F**<br>5.1 V 稳压管，**SOD-123** | `C151588` | **数据线钳位**（2026-09-06 补）。与官方 HAT 的 `D4` **同型号不同封装** —— HAT 用 `BZT52C5V1S`（SOD-323，`C151348`），本板改用 **SOD-123**（`C151588`）便于返修。<br>阴极接 `DXL_BUS`、阳极接地。飞特信号高电平规格是 2–5 V，74LVC 输入耐 5.5 V 本身不会坏，但此前**没有任何对付线上尖峰的器件**；舵机带电插拔是常态 |
| **D1** | **TVS `SMF12A`**，SOD-123FL | `C2943870` | ⚠️ **必须贴在 3P 连接器旁**。截止 **12 V** > 满电 8.4 V（正常工作不漏电）；击穿 13.3–14.7 V；**钳位 19.9 V** < C6 的 25 V。峰值功率 200 W。<br>封装 3.7 × 1.8 mm，比 SMA 小一半。要更大耐量可换 SMA 版 `SMAJ12A`（400 W）：ST `C132952` / Littelfuse `C148213` |
| **F1** | **PPTC `MF-NSMF020X-2`**，BOURNS，1206 | `C210358` | 本板故障时不拖垮整条舵机总线（官方 HAT 用 TH1 100R 热敏是同一思路）。<br>**额定 24 V**（母线 8.4 V，余量 2.9×）· 保持 **200 mA** · 跳闸 460 mA · 跳闸时间 0.6 s · AEC-Q200。<br>⚠️ **别选 0805 的常见型号** —— 那一档大多只有 **6 V** 额定（如 `0805L150SLYR`，而且它是 1.5 A 不是 150 mA），挂 8.4 V 母线直接不合格。**PPTC 的电压等级是硬约束** |
| J4 | 2×2 或 1×4 排针（可选，DNP） | — | 把 IMU 的 SPI 四线引出。将来若改成 SPI 直连主控，MCU 不贴、飞线即可，不用推翻整块板 |

#### 时钟：这个封装接不了无源晶振

查 **DS12992 Rev 3, Table 12「Pin assignment and description」(p.36)**，TSSOP20 那一列：

| 脚 | 名字 | 附加功能 |
|---|---|---|
| 2 | `PC14-OSC32_IN` | `OSC32_IN`, **`OSC_IN`** |
| 3 | `PC15-OSC32_OUT` | `OSC32_OUT`（**没有 `OSC_OUT`**）；交替功能里有 `OSC_EN` |

`PF0-OSC_IN` / `PF1-OSC_OUT` 在 TSSOP20 这一列是 `-`，**没引出来**。无源晶振要
`OSC_IN` + `OSC_OUT` 两个脚才能起振，所以：

| 方案 | 可行性 |
|---|---|
| 无源高速晶振（8/16 MHz + 两颗电容） | ❌ 没有 `OSC_OUT` |
| **有源晶振走 HSE 旁路**（单端时钟灌进 2 脚） | ✅ 3 脚还能当 `OSC_EN` 使能它 |
| 32.768 kHz 无源晶振（LSE） | ✅ 2/3 脚都有，但 **LSE 不能给 PLL 供时钟**（手册 p.21：PLL 只能吃 HSE 或 HSI16），只能拿来校准 HSI16 |

**默认用 HSI16。** 手册 **Table 41 (p.64)** 的数据：

| 项 | 条件 | 范围 |
|---|---|---|
| 出厂频率 | V<sub>DD</sub> = 3.0 V, T<sub>A</sub> = 30 °C | 15.88–16.08 MHz，即 **−0.75% / +0.5%** |
| 温漂 | 0 ~ 85 °C | **±1%** |
| 温漂 | −40 ~ 125 °C | −2% / +1.5% |
| 电压漂移 | 1.62–3.6 V | ±0.1%（可忽略） |

叠加后 0–85 °C 内最坏约 **−1.85% / +1.55%**。1 Mbps 异步 UART 的典型容差在 ±3% 量级，
主机侧（树莓派）是晶振精度、基本不占预算 —— **能跑，但吃掉约三分之二的余量**。

→ 原方案是**留出晶振位、默认不贴（DNP）**，出问题再拿烙铁焊上去。
**2026-09-07 改为默认贴片**，理由见下面「为什么从 DNP 改成贴片」。

##### 时钟位（2026-09-07 起**默认贴片**）

| 位号 | 器件 | 立创编号 | 说明 |
|---|---|---|---|
| **X1** | **F322516MUBCE2O**（雅晶鑫）<br>16 MHz **有源晶振** · CMOS · 1.8–3.3 V · ±10 ppm 常温 · **5 mA** · SMD3225-4P | `C5917307` | 走 **HSE 旁路**。脚位 `1=OE / 2=GND / 3=OUT / 4=VDD`。<br>**选它是因为 5 mA 是同封装候选里最低的** —— 见下方「为什么挑 5 mA 那颗」 |
| **C9** | 100 nF 0603 | `C14663` | X1 的 VDD 去耦，**贴着 X1 的 4 脚放**（实测 2.39 mm） |
| **R3** | 33 Ω 0603 | `C23140` | 时钟输出**源端串联阻尼**。16 MHz 方波边沿陡，一段走线就够产生振铃和 EMI。要省可换 0 Ω |

> 原选型是 `C387369`（星通时频 S3D16.000000B20F30T，10 mA）。下单时发现
> **立创贴片备料库没有这颗**（被归到「使用私有库存的元器件」，私有库 0），故更换。

###### 为什么从 DNP 改成贴片

DNP 的原始理由本身成立：HSI16 最坏 −1.85%/+1.55%，1 Mbps UART 容差 ±3%，够用；
固件还能用定时器输入捕获反调 `HSITRIM`，误差压到 0.3% 以内。

**但那套 `HSITRIM` 自校准固件一行都还没写。** 第一版板子从没上电过，真出现通信误码时，
「是 HSI16 漂了还是固件写错了」会是个纯浪费时间的分叉。一颗 ¥1.9 的晶振把这个分叉直接砍掉
—— **第一版能用钱买掉的不确定性都该买掉。**

###### 为什么挑 5 mA 那颗

同封装的候选精度都远远够用（要替代的 HSI16 是 ±18500 ppm，随便哪颗都好一千倍），
**唯一跟本板设计有互动的参数是工作电流**：

```
板上原本总电流 5–10 mA  →  LDO 压降 5.1 V  →  耗散约 51 mW
选 5 mA 晶振  → 总 11 mA → 56 mW → SOT-89 结温升 6~9 °C
选 10 mA 晶振 → 总 16 mA → 82 mW → 结温升 8~13 °C
```

两者都安全（F1 是 200 mA 保持，远不到），但**耗散翻倍会直接叠在评审提的
「LDO 发热影响 IMU」那条上**。5 mA 那颗只贵 ¥0.4，没有理由选 10 mA 的。

###### ⚠️ 换料时的陷阱：四脚同封装，引脚定义相反

立创搜 `3225` 出来的**绝大多数是无源晶体**，其中 `C13738`（YSX321SL，基础库、
免换料费、十几万现货）看起来最像 —— 同样 SMD3225-4P、同样四个焊盘。
**但它贴上去，一上电就是 3.3 V 对地短路。**

| 脚 | 有源晶振（本板按此画） | 4 脚无源晶体 |
|---|---|---|
| 1 | 使能 OE | 晶体端子 |
| 2 | GND | **金属外壳（接地）** |
| 3 | 输出 OUT | 晶体端子 |
| 4 | **VDD** | **金属外壳（接地）** |

无源晶体的 2 脚和 4 脚是同一片金属盖、内部短接。本板 `X1.2 = GND`、`X1.4 = 3.3V`，
贴上去等于用那片盖子把 3.3 V 和地连起来。

**换料时只认「有源晶振 / 振荡器 / OSC」这个标签**，写 `XTAL` / `晶体谐振器` /
`无源` 的一律不行。而且这条不是可选项 —— G031 的 TSSOP-20 **没引出 `OSC_OUT`**，
无源晶振在这颗 MCU 上本来就接不了。

接法：

```
                     3.3V
                       │
   3.3V ── 1 OE   VDD 4 ┴── C9 100nF ── GND
           ┌───────────┐
           │    X1     │
           └───────────┘
    GND ── 2 GND  OUT 3 ── R3 33Ω ── OSC_IN ── U1 脚2 (PC14/OSC_IN)
```

`OE` 也可以改接 U1 脚 3（`PC15` 的 `OSC_EN` 交替功能）做软件使能，但那样固件要多管一件事，
默认直接接 3.3 V 常开。

> ⚠️ **这三颗都不进 BOM、但要进 PCB** —— 嘉立创下单时不会给你贴、也不收料钱，
> 焊盘照样在板上。原理图里已按 `Add into BOM = no` / `Convert to PCB = yes` 设好。

#### 封装口径：阻容一律 0603，不用 0402

**2026-09-06 决定**：所有阻容从 0402 改为 **0603**，D2 从 SOD-323 改为 **SOD-123**。

理由不是「手焊不了 0402」——这块板上有 **LGA-14 的 LSM6DSV16X**（底部焊盘，
3 × 2.5 mm），本来就必须上热风或回流，有了那套工具 0402 也不难。

**真正的理由是调试期返修**：串阻要从 150 Ω 试到 33 Ω、某个上拉要摘掉、
去耦要加一颗——这些改动在 0603 上拿烙铁几秒钟就能做，0402 得重新架热风。
一块没打样验证过的板子，第一版必然要改几次。

代价很小：板上 11 个 0402 换成 0603，多占约 16 mm²，
不到 45 × 22 mm 板面积的 2%。而且 **0603 这几个值全在立创基础库**
（10 kΩ `C25804`、150 Ω `C22808`、33 Ω `C23140`、100 nF `C14663`），
比原来 0402 的扩展库料还省上料费。

> C6（10 µF/25 V）保持 0805，C5（4.7 µF）和 C7（10 µF）本来就是 0603。

#### 板框与安装

官方**没有公开这块板的任何几何**（MJCF 里没有它的网格）。唯一的物证是固定它的打印件
`banana_pcb_locker`，实测反推：

| 量 | 值 | 来源 |
|---|---|---|
| 锁扣总长 | **54.05 mm** | 网格实测 |
| **两个定位耳中心距** | **≈ 34 mm** | 按 X 切片统计耳片位置 |
| 每个耳片 | ≈ 4 × 2.3 × 2.0 mm | 同上 |
| 主体弧高 | 6.7 mm（Z 48.97→55.63） | 这就是「香蕉形」的由来 |

→ 推断原版板：**两个安装点间距 34 mm、长边 ≤ 54 mm、外形是弧的**。

> 💡 **但锁扣本身是打印件**（`print/打印件/`，打 1 个）—— 所以**板框和锁扣可以一起重新设计**，
> 不必迁就原版的弧。原版做成弧大概是为了贴合躯干内壁省空间；自己复刻用**直板 + 改锁扣**
> 简单得多，弧形 PCB 布线和拼板都麻烦。

**建议板框：40 × 18 mm（宽松则 45 × 22），两个 M2 安装孔间距 34 mm，2 层板。**

- 元件净面积约 230 mm²（连接器主导：两个 JST EH 3P 各约 10 × 6 mm），
  两层板按 2–3 倍算需 460–700 mm² → 40 × 18 = 720 mm² 刚好
- 孔距保持 34 mm，**可直接用原版打印锁扣**
- ⚠️ **别为省钱压尺寸**：嘉立创 2 层板 100 × 100 mm 以内同价，画 25×20 和画 50×50 花一样的钱。
  尺寸只该由装配约束决定
- ⚠️ **注意元件高度**：锁扣内腔高 6.65 mm，而 JST EH 直插连接器本体高约 8 mm ——
  要么用卧式（side entry）封装，要么这块板根本不是被那个锁扣压的

#### 布局要点（比加器件更管用，而且不花钱）

**板型：2 层板，45 × 22 mm，贴片件全部放正面。**

| 决定 | 为什么 |
|---|---|
| **2 层足够** | 十几个器件、1 Mbps 不算高速。**最需要的是完整地平面**，2 层底层整片铺地就能做到，比多两层重要得多。成本上 2 层比 4 层便宜数倍 |
| **贴片件全在正面** | ① SMT 打样只贴一面，**费用直接减半**（双面要过两次炉）② 底层不被元件和过孔打断，**地平面完整** |
| **连接器 THT，排在同一条边** | `B3B-EH-A` 与 SWD 排针都是插件。留着自己手焊能省一笔插件费（脚大、间距 2.5 mm，很好焊）。<br>⚠️ 但过孔会在底层地平面上开洞 —— **三个连接器都排在同一侧**，洞就集中在一边，不会把地平面切碎 |
| 45 × 22 而不是 40 × 18 | 单面布局需要 2–3 倍元件净面积（约 230 mm²）→ 460–700 mm²。45×22 ＝ 990 mm² 宽裕。<br>**反正嘉立创 100 × 100 以内同价，没必要压尺寸** |

**给 IMU 的三条（数据手册要求 + 常识，不花钱）：**

1. **`VDD` 与 `VDDIO` 各自 100 nF 就近去耦** —— 手册明确要求
2. **完整地平面，IMU 正下方不走高速线**
3. **IMU 的电源走线与 UART 收发部分分开**

> **不做电气隔离。** 官方 HAT 上的音频 codec、BMI088、ToF 全都直接挂同一套电源，零隔离，
> 而机器人是能走的。更关键的是：真隔离要独立电源，这块板就不能从总线取电了 ——
> **"挂在总线上的第 16 个设备"这个设计前提就没了。**
>
> 💡 电源入口留一个 **0 Ω 跳线位**：默认贴 0 Ω 直通；将来实测发现电源噪声影响陀螺读数，
> 换成磁珠即可。成本一样，风险为零 —— 直接放磁珠反而可能与大电容形成 LC 谐振，放大某个频段。

#### ⚠️ 过压保护：它和舵机共用一条母线

**这是这块板最容易被忽略的风险。** 15 个舵机挂在同一条 `+BATT` 上，减速、反转、堵转释放时
**反电动势会把母线抬高**；这块板挂在总线末端，线缆电感加上快速换向，输入端看到的尖峰比电池端更凶。

> 注意威胁的性质是**正向过压，不是反接** —— 所以串联二极管不解决这个问题。

三道防线，按重要性排：

| 防线 | 器件 | 挡什么 | 状态 |
|---|---|---|---|
| **① 宽压 LDO** | `HT7533-1`（工作 30 V / 极限 33 V） | 持续过压。8.4 V 母线即使被抬到 17 V 也纹丝不动，**余量 3.5×** | ✅ 已选 |
| **② TVS** | `SMAJ12A`，**贴在连接器旁** | µs 级尖峰。截止 12 V > 满电 8.4 V（不漏电），钳位 19.9 V < C6 的 25 V | ⚠️ 本次补入 |
| **③ PPTC** | hold 100–200 mA | 本板短路时不把整条总线拉垮 —— 15 个舵机跟着掉电，机器人直接摔 | ⚠️ 本次补入 |

> **TVS 的位置比型号更重要**：要贴在 3P 连接器旁边，越靠近入口越好。放到 LDO 边上就晚了 ——
> 尖峰已经在板上跑了一圈。
>
> ⚠️ **反电动势的实际幅度本仓库没有实测**，取决于线缆电感与换向速度。舵机到货后拿示波器
> 在总线上量一次，再回来核对这里的选型。

> ⚠️ **另外两个坑，都会烧板：**
>
> **1. LDO 耐压。** 总线满电 8.4 V，常见型号全部不够（下列为**工作电压上限 / 绝对最大值**）：
> AP2112K **6.0 / 6.5 V**、ME6211 **6.0 / 6.5 V**、TLV75533 **5.5 / 6.0 V**。
> 必须选 HT7533-1（工作 30 V，绝对最大 33 V）或同级。
>
> **2. 输入电容耐压 —— 此前本表选错了。** `C19702` 是 **10 V** X5R，挂在 8.4 V 总线上
> 只剩 1.2× 余量，且 X5R 在 8.4 V 直流偏置下**实际容量不到标称的一半**，还要承受舵机
> 启停的瞬态。**C6 必须换 ≥25 V 料号**（0805 更稳妥）；C7 在 3.3 V 输出侧，10 V 够用。

---

## 五、机械件

### 轴承（共 14 个）

| 规格 | 数量 | 依据 |
|---|---|---|
| **Ø22 × 16 × 4** | **11** | `seeed_bearing__configuration__22x16x4` 引用 11 次 |
| **Ø15 × 10 × 3** | **3** | `seeed_bearing__configuration_default` 引用 3 次 |

### 紧固件（M2 为主，约 325 件）

整机 M2 级孔（Ø1.9–2.5 mm、包角 ≥300°）**按装配体用量加权共 237 个**，
其中 **60 个在舵机本体上**（15 × 4）、21 个在轴承/PCB/电池等标准件上，
**结构件上约 156 个**。

> ⚠️ **口径说明**：本仓库早期写的「213 个」复算不出来，已更正为 237。
> 差异来自两点：早期统计**没有按装配体用量加权**（`leg` 实际 ×4、`hip_l` ×2 等），
> 且**混入了未使用的网格**。孔径分布表与本数字口径不同，见 [紧固件反推](docs/紧固件反推.md)。
>
> 下面的采购量按 325 件给，对 237 个孔位仍有 **1.37×** 余量，**不影响下单**。

| 规格 | 建议数量 | 用途 |
|---|---|---|
| M2×4 内六角圆柱头 | 60 | 薄壁位 |
| M2×6 内六角圆柱头 | **80**（主力） | |
| M2×8 内六角圆柱头 | 40 | 孔深 3–5 mm |
| M2×12 内六角圆柱头 | 15 | 少量深孔 |
| M2 螺母 | 50 | 无攻丝处 |
| **M2 热熔螺母** | **60** | 打印件推荐，比直接攻丝牢得多 |
| M2.5×6 | 20 | 少量 Ø2.7 孔位 |

推导过程见 [紧固件反推](docs/紧固件反推.md)。

### 打印件（30 种 / 41 件）

**注意数量 —— 有 9 种要打多份：**

| 零件 | 打几个 |
|---|---|
| `leg_腿部` | **×4** |
| `hip_l_髋部左` | ×2 |
| `neck_颈部` | ×2 |
| `power_support_电源支架` | ×2 |
| `sole_left_左脚底` | ×2 |
| `sole_right_右脚底` | ×2 |
| `upper_leg_rigidity_plate_上腿加固板` | ×2 |
| `yaw2roll_偏航转横滚` | ×2 |
| `bearing_roll_横滚轴承压盖` | ×2 |
| 其余 21 种 | 各 ×1 |

**软性材料件**（从命名和用途判断，建议 TPU）：`jaw_soft_软下巴`、`soft_mouth_top_软嘴顶部`

⚠️ **别搞混左右**：`upper_leg_left` 和 `upper_leg_right` 是镜像件（质心 X = **±0.006766 m ＝ ±6.77 mm**，质量同为 0.0482067 kg），
两个都要打；`ankle_left`/`ankle_right`、`sole_left`/`sole_right`、`foot_left`/`foot_right` 同理。

文件与分类见 [`print/`](print/)。

### 轮滑变体（可选，另计）

想复刻轮滑功能，需**额外**打印并替换：

| 零件 | 数量 |
|---|---|
| `tire_轮胎` | **×8** |
| `rim_轮辋` | **×4** |
| `roller_blade_滚轮叶片` | ×2 |
| `ankle_l_v1` / `ankle_r_v1` | 各 ×1（**替换**掉标准脚踝） |

⚠️ **轮滑脚踝比标准脚踝高 10 mm**（46.5 vs 36.5），两套不能混用。

见 [`print/变体-轮滑/`](print/变体-轮滑/)。

---

## 六、还没解决的空白

复刻到最后会卡在这两处，公开资料给不出答案：

1. **电池取电触点。** CAD 里只有打印件 `power_support`（×2），**没有任何触点 PCB 或簧片的模型**。
   官方用金属簧片还是市售 NP-F 转接板，判断不了。最省事的办法是买现成的 NP-F 电池转接板。
2. **线束。** 舵机之间的 Dynamixel 3P 连接线长度、摄像头 MIPI 排线长度，官方没有任何图纸。
   舵机一般自带短线，但机器人内部走线长度要实测。

---

## 数据来源

| 数据 | 来源 |
|---|---|
| 零件数量 | 上游 `robot_walk.xml` 的 geom `mesh=` 引用计数 |
| 轮滑变体数量 | 上游 `robot_groundcontact_rollers.xml` |
| 螺丝数量 | STL 孔位几何反推，见 [紧固件反推](docs/紧固件反推.md) |
| 电子件型号 | Rust 源码、设备树、`robotd.toml`，见 [硬件方案逆向](docs/硬件方案逆向.md) |
| HAT 板参数 | 官方 KiCad 工程与 `production/` 生产文件 |
| 舵机规格 | [Robotis e-manual](https://emanual.robotis.com/docs/en/dxl/x/xl330-m288/) |
| 立创编号 | 嘉立创 EDA 元件库实时查询 |

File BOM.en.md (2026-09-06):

# Bill of Materials

> ⚠️ **This English version lags behind the Chinese original.** Several corrections (camera rotation, MK1 part number, U10 placement, STS3032 torque basis, board SKU) were applied to the Chinese docs first. **When the two disagree, the Chinese version wins.** Last sync: 2026-09-05.

[简体中文](BOM.md) · **English**

Everything needed to build one Microduck. Quantities come from geom references in upstream
`robot_walk.xml` (**38 mesh types / 75 instances**) — counted, not estimated.

> ⚠️ **Pollen have never published a BOM.** This list is reconstructed from the public MJCF, STLs,
> Rust source and KiCad project. Every entry cites its basis. Prices vary enormously by region and
> date — treat them as **order of magnitude only**.
>
> Checked: **2026-09-04**. Upstream baseline: `pollen-robotics/microduck_rl` @ **`29e887e`**
> (includes the full CAD re-export `8dfc08f` of 2026-09-01).
> The geom counts in `robot_walk.xml` are **identical before and after** that re-export
> (38 types / 75 instances), so the quantities here are unaffected.

---

## 1. Cost at a glance

| Category | Qty | Order of magnitude |
|---|---|---|
| **Servos** | 15 | **$359 – €629** (huge regional spread, see below) |
| Compute and sensors | 4 items | ~$80 – 120 |
| Battery and power | 2 items | ~$30 – 50 |
| Bearings | 14 | ~$15 – 30 |
| Fasteners | ~325 pieces | ~$15 – 25 |
| **PCB fabrication (2 boards)** | 2 | ~$60 – 150 with assembly |
| Filament | — | ~$15 – 30 |

**The servos dominate**, and the channel spread is enormous: ROBOTIS international at $23.90 ×15 is
**$359** (below the robot's retail price), ROBOTIS US at $27.49 is **$412** (about equal to it), and
European inc-VAT retail runs **€603–629** (far above).

> $399 is Seeed-scale manufacturing with Pollen's supply chain. **An individual build cannot reach it.**

---

## 2. Servos (the cost centre)

| Part | Qty | Basis |
|---|---|---|
| **Dynamixel XL330-M288-T** | **15** | the `xl330` mesh is referenced 15× in `robot_walk.xml` |

- 14 are in the policy action space; the **15th drives the beak/jaw** through `passive_*` linkages
- IDs: left leg 20–24 / neck-head-mouth 30–34 / right leg 10–14
- ⚠️ **The model number is inferred.** The source only carries `motor_name="xl330"` with no suffix.
  Evidence for M288-T: [actuator selection](docs/actuator-selection.en.md#how-the-model-number-was-pinned-down)

**Prices** (2026-09-04):

| Source | Each | ×15 |
|---|---|---|
| Robotis US | **$27.49** | **$412** |
| Generation Robots (EU, ex-VAT) | €33.50 | €503 |
| Generation Robots (EU, inc-VAT) | €40.20 | €603 |
| MyBotShop | €41.95 | €629 |

> ⚠️ **Over-voltage warning**: the XL330 is rated 3.7–6.0 V, and Microduck feeds it 6.6–8.2 V.
> This is Pollen's deliberate choice, not a typo. See
> [the voltage truth](docs/actuator-selection.en.md#-the-voltage-truth-the-xl330-is-run-over-voltage).

---

## 3. Electronics

| Part | Model | Qty | Basis / note |
|---|---|---|---|
| Compute | **Radxa Zero 3W** | 1 | device tree `compatible = "radxa,zero-3w"`. ⚠️ Several RAM/eMMC SKUs — the official spec page (2026-08-27) states **1 GB / 32 GB**, though the source tree carries no SKU evidence; **2G/16G recommended for a replica**. the OS image must carry the Rockchip vendor kernel (Armbian family) or the NPU does not exist |
| Camera | Raspberry Pi Camera v2 (**IMX219**) | 1 | `setup-board.sh` applies the `radxa-zero3-rpi-camera-v2` overlay. ⚠️ **Mounted off-axis; corrected in software.** `media-bringup.md` says the alpha was upside down (`180`), but the current code default in `mediad/src/main.rs` is `--rotate 90`. Check against your build |
| Depth | **VL53L8CX** or VL53L5CX module | 1 | firmware supports both, identified by revision ID; address `0x29` or `0x52`; Stemma/Qwiic |
| Battery | **Sony NP-F550** (2S, 7.4 V) | 1 | ⚠️ see correction below |
| Battery holder | Any NP-F series holder | 1 | Upstream only has the printed `power_support` — **no contact model at all**; you must solve the pickup yourself |
| Speaker | Small loudspeaker | 1 | `speaker` mesh ×1; the HAT carries a PAM8406 amplifier and Wago terminals |

### ⚠️ Battery correction: it is an NP-F550, not an F970

The upstream mesh is named `np_f970`, **and that is misleading**:

| | |
|---|---|
| Measured mesh bounding box | **70.8 × 38.6 × 20.6 mm** ← NP-F550/F570 dimensions |
| A real NP-F970 | ~**60 mm** thick, ~300 g |
| Model named in the source | **only ever NP-F550** (`model.rs`, `robotd-design.md`); F970 appears nowhere |

**An F970 will not fit, and 300 g eats more than a third of the 800 g budget.**
Earlier versions of this repository said "NP-F970" in several places; corrected throughout.

---

## 4. Circuit boards (2, both need fabricating)

### Board 1: RPI Robot HAT — published; download and order

| | |
|---|---|
| Source | [`pollen-robotics/elec_RPI_Robot_HAT`](https://github.com/pollen-robotics/elec_RPI_Robot_HAT) (Apache-2.0) |
| Production files | `production/`: Gerbers, BOM, pick-and-place, schematic PDF, STEP |
| **Layers** | **4** (`F.Cu / In1.Cu / In2.Cu / B.Cu`) |
| **Thickness** | **1.0 mm** (KiCad `(thickness 1)`. The 0.84 mm measured from the STL is a simulation-mesh approximation — order to the KiCad value) |
| Size | **65.0 × 30.9 mm** (measured from KiCad `Edge.Cuts`, R3.5 corners) — 0.9 mm wider than a Pi Zero |
| BOM | 47 lines / **123 parts**, of which **5 lines are DNP** |
| Placements | **117 rows** in `POS.csv`, including 3 fiducials (FID1–3) and H3 → **113 actual components** |
| Hand-solderable? | ❌ **No** — VQFN-32 codec and LGA-16 IMU. Order with assembly |

**Key parts** (for costing and substitution):

| Ref | Part | Function |
|---|---|---|
| U2 | TLV320AIC3104IRHBR | Audio codec (I²C `0x18`) |
| U1 | PAM8406D | Class-D amplifier |
| MK1 | MEMS microphone (LCSC `C7587901`) | On-board. ⚠️ Official BOM gives no part number; the earlier LMA2718 has been withdrawn |
| U11 | BMI088 | IMU — **fitted but unused by software** (the so-called "second IMU") |
| U8 | SIT3088E | RS-485 transceiver |
| U10 | LM5050-1 | Ideal diode (reverse protection) |
| U9 | AP63205 | Buck converter |
| U4 | CAT24C32 | EEPROM — **DNP**, so this is not a self-identifying HAT |
| J13/J14 | JST EH 3P | Dynamixel **TTL** |
| J3/J11 | JST EH 4P | Dynamixel **RS-485** |
| J5–J8 | JST SH 1 mm 4P | Qwiic / Stemma (for the ToF) |

⚠️ **Before you order:**

1. **There is no charging circuit and no USB-C input on this board.** The
   `pwr_supply_charge.kicad_sch` in the repository is an **orphan sheet** (`main.kicad_sch` never
   instantiates it; its title block still names another project). Charge the battery externally.
2. **Opening the KiCad project requires [`lib_KiCAD`](https://github.com/pollen-robotics/lib_KiCAD)**,
   or it loads as unresolved symbols. Not needed if you only fabricate — use the Gerbers.

### Board 2: `imu_to_dxl` — no public project exists; you must design it

| | |
|---|---|
| Status | 🔧 **being rebuilt in this repository**, see [teardown §3](docs/hardware-teardown.en.md) |
| Function | Presents an IMU as a Dynamixel slave (ID **200**) on the servo bus |

**Reference BOM** (this repository's design, not official):

| Ref | Part | LCSC | Note |
|---|---|---|---|
| U1 | **STM32G031F8P6** | TBD | MCU, TSSOP-20. ⚠️ **This is our suggestion, not a reverse-engineered fact** — the official board's MCU cannot be recovered. F8 (64 KB) over F6 (32 KB) leaves headroom for dual-protocol firmware |
| U2 | **LSM6DSV16XTR** | `C5267406` | 6-axis IMU with SFLP fusion, LGA-14 |
| U3 | **SN74LVC2G241DCUR** | `C10430` | Tri-state buffer for single-wire half-duplex |
| U4 | **HT7533-1** | `C14289` | 3.3 V LDO, **30 V input rating** (JLC basic part — no setup fee) |
| J1/J2 | B3B-EH-A(LF)(SN) | `C160259` | Dynamixel 3P — **same part as the official HAT**, cables interchange |
| J3 | PZ254V-11-04P | `C2691448` | SWD header |
| C1–C5 | 100 nF 0402 | `C307331` | Decoupling (same part as the official HAT) |
| **C6** | 10 µF **≥25 V** | ⚠️ TBD | **LDO input** — sits directly on the 8.4 V bus |
| C7 | 10 µF 0603 10 V | `C19702` | LDO output (3.3 V); 10 V is fine here |
| R1/R2 | 10 kΩ 0402 | `C25744` | CS pull-up (**mandatory**), NRST pull-up |

> ⚠️ **Two traps on the input side, both of which destroy the board:**
>
> **1. LDO rating.** The bus reaches 8.4 V fully charged; the usual suspects fall short
> (shown as **operating limit / absolute maximum**): AP2112K **6.0 / 6.5 V**,
> ME6211 **6.0 / 6.5 V**, TLV75533 **5.5 / 6.0 V**. Use the HT7533-1 (30 V operating,
> 33 V absolute) or equivalent.
>
> **2. Input capacitor rating — this table previously got it wrong.** `C19702` is a **10 V**
> X5R. On an 8.4 V bus that is only 1.2× margin, and an X5R at 8.4 V DC bias retains **less than
> half its nominal capacitance** — before the servo switching transients. **C6 must be a ≥25 V
> part** (0805 is safer); C7, on the 3.3 V output, is fine at 10 V.

---

## 5. Mechanical

### Bearings (14 total)

| Size | Qty | Basis |
|---|---|---|
| **Ø22 × 16 × 4** | **11** | `seeed_bearing__configuration__22x16x4` referenced 11× |
| **Ø15 × 10 × 3** | **3** | `seeed_bearing__configuration_default` referenced 3× |

### Fasteners (mostly M2, ~325 pieces)

Across the assembly there are **237 M2-class holes** (Ø1.9–2.5 mm, ≥300° wrap), weighted by how
many times each part is used: **60 in the servo bodies** (15 × 4), 21 in bought parts
(bearings / PCBs / battery), and **about 156 in printed structural parts**.

> ⚠️ **On the figure**: earlier versions of this repository said "213", which does not reconcile;
> corrected to 237. The gap came from two things — the earlier count was **not weighted by usage**
> (`leg` is actually ×4, `hip_l` ×2, and so on) and it **included unused meshes**. The
> diameter-distribution table uses a different basis; see
> [fastener reconstruction](docs/fastener-reconstruction.en.md).
>
> The quantities below total 325 pieces — still **1.37×** cover for 237 holes, so ordering is unaffected.

| Size | Suggested qty | Use |
|---|---|---|
| M2×4 socket cap | 60 | thin walls |
| M2×6 socket cap | **80** (the workhorse) | |
| M2×8 socket cap | 40 | 3–5 mm hole depth |
| M2×12 socket cap | 15 | a few deep holes |
| M2 nuts | 50 | where nothing is tapped |
| **M2 heat-set inserts** | **60** | recommended for printed parts — far stronger than tapping |
| M2.5×6 | 20 | a few Ø2.7 holes |

Derivation: [fastener reconstruction](docs/fastener-reconstruction.en.md).

### Printed parts (29 types / 39 pieces)

**Watch the quantities — 8 types need more than one:**

| Part | Print |
|---|---|
| `leg_腿部` | **×4** |
| `hip_l_髋部左` | ×2 |
| `neck_颈部` | ×2 |
| `power_support_电源支架` | ×2 |
| `sole_left_左脚底` | ×2 |
| `sole_right_右脚底` | ×2 |
| `upper_leg_rigidity_plate_上腿加固板` | ×2 |
| `yaw2roll_偏航转横滚` | ×2 |
| The other 21 types | ×1 each |

**Flexible-material parts** (from naming and function — TPU suggested):
`jaw_soft_软下巴`, `soft_mouth_top_软嘴顶部`

⚠️ **Do not confuse left and right.** `upper_leg_left` and `upper_leg_right` are mirrored
(centroids +0.067 / −0.067) — you need both. Same for `ankle_*`, `sole_*`, `foot_*`.

Files: [`print/`](print/).

### Roller-skate variant (optional, extra)

To reproduce the skating function, print **additionally** and substitute:

| Part | Qty |
|---|---|
| `tire_轮胎` | **×8** |
| `rim_轮辋` | **×4** |
| `roller_blade_滚轮叶片` | ×2 |
| `ankle_l_v1` / `ankle_r_v1` | ×1 each (**replaces** the standard ankles) |

⚠️ **The skate ankles are 10 mm taller** than the standard ones (46.5 vs 36.5). The two sets are
not interchangeable.

See [`print/变体-轮滑/`](print/变体-轮滑/).

---

## 6. Still unsolved

Two things will stop you at the end, and public material cannot answer them:

1. **Battery contacts.** The CAD has only the printed `power_support` (×2) — **no contact PCB or
   spring model of any kind**. Whether Pollen use metal springs or an off-the-shelf NP-F adapter
   cannot be determined. The easy route is a commercial NP-F adapter plate.
2. **Cable harness.** No drawings exist for the Dynamixel 3P cable lengths or the camera MIPI
   ribbon. Servos ship with short cables, but internal routing lengths must be measured on the build.

---

## Sources

| Data | Source |
|---|---|
| Part quantities | geom `mesh=` reference counts in upstream `robot_walk.xml` |
| Skate-variant quantities | upstream `robot_groundcontact_rollers.xml` |
| Screw counts | hole geometry from the STLs — see [fastener reconstruction](docs/fastener-reconstruction.en.md) |
| Electronics part numbers | Rust source, device tree, `robotd.toml` — see [teardown](docs/hardware-teardown.en.md) |
| HAT board figures | the official KiCad project and `production/` files |
| Servo specification | [Robotis e-manual](https://emanual.robotis.com/docs/en/dxl/x/xl330-m288/) |
| LCSC part numbers | live query against the EasyEDA component library |

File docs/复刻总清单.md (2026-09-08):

# Microduck 复刻总清单 —— 打什么、买什么、花多少、怎么省

> **⭐ 2026-09-07 起以 [物料清单-进度快照](物料清单-进度快照.md) 为准**（舵机/主控/外壳已购，剩 ≈¥560 分两批）。本页保留作为价格依据与店铺实链的总账。

> 一页回答五个问题：**打印什么 / 还缺什么 / 买什么去哪买 / 总成本 / 怎么最省**。
> 本文是汇总层，明细都在链接的文档里。价格快照 **2026-09-04**（随时间失效，下单前复核）。
> 标签：✅ 文件已齐可直接用 ｜ ⬜ 文件还缺 ｜ 💰 价格来自仓库采购清单实测快照

---

## 一、要打印的文件（全部已齐 ✅）

| 文件 | 数量 | 状态 |
|---|---|---|
| [`print/打印件/`](print/打印件/) 30 种结构件 | **41 件**（9 种打多份，数量表见 print/README） | ✅ 全部水密可切（[体检报告](docs/打印就绪检查.md)），最大件 91.8×122.7×46.3mm |
| [`print/测试片/`](print/测试片/) 3 个定标件 | 3 | ✅ **本批新补**（此前缺）：M2 孔径阶梯 + Ø22/Ø15 轴承压入档，图例见目录内 README |
| [`print/变体-轮滑/`](print/变体-轮滑/) 轮滑替换件 | 可选 15 件 | ✅ 不做轮滑不打 |
| `print/标准件-无需打印/` | 8 | ✅ 仅供对位，**不打** |

**打印顺序**（30 天计划 D6 起）：测试片 → 腿部全套（已试装验证过）→ 壳体 → 头颈。

## 二、还缺的文件（诚实清单）

| 缺什么 | 状态 | 怎么解决 |
|---|---|---|
| `imu_to_dxl` 原理图 + PCB（EDA 工程文件） | ⬜ **唯一真正要画的板** | 规格已 100% 备齐（[设计包](docs/imu_to_dxl-设计包/设计规格.md)：引脚/时序/BOM/固件协议层已测试），剩嘉立创 EDA 画图 ~1 天 |
| HAT 板生产文件 | ✅ 不缺 | 官方 Gerber/BOM/贴片坐标直接下载（`elec_RPI_Robot_HAT`，Apache-2.0） |
| 线束长度表 | ⬜ 官方无任何资料 | 舵机自带短线 + [5264 连接线](https://item.taobao.com/item.htm?id=587191439333)买多长度档现场配（¥2/条） |
| 电池取电触点 | ✅ 已用现成品顶掉 | 官方无触点模型 → 买 NP-F 供电扣板 ¥19（见采购表） |
| 喇叭具体型号 | ⬜ 未定 | 5W 任意小喇叭接 HAT Wago 端子（省 HAT 则不需要） |
| `lens`/`m12_lens_holder` 归属 | ⚠️ 存疑 | `m12_lens_holder` 已在打印件里，镜头本体随 IMX219 模组自带，待实物复核 |
| 官方 9 个运动策略 ONNX | ✅ 不缺 | 官方公开，**硬件保持同款即可直接用**（这是最大的省钱前提） |

## 三、购买清单（在哪买、多少钱）

> 明细与全部备选店铺：[电控采购清单](docs/电控采购清单.md)（淘宝实链）· [机械采购清单](docs/机械采购清单.md)。下表是每类的**推荐单一选择**。

### 电子（无 HAT 路线）

| 项 | 推荐渠道 | 价格 |
|---|---|---|
| 主控 Radxa Zero 3W（2G/16G） | **官方分销 ALLNET China**（淘宝溢价 3–6 倍，别买） | 💰 ¥237 |
| 摄像头 IMX219 | DECXIN 旗舰店 | 💰 ¥32.8 |
| CSI 排线 15→22pin 4cm | 汇博视捷 | 💰 ¥1.88 |
| ToF VL53L8CX（⚠️ 不是 L0X/L7CX） | 森科源 | 💰 ¥70 |
| NP-F550 电池（⚠️ 不是 F970） | 唯卓仕（首单价） | 💰 ¥52.8 |
| NP-F 供电扣板（解决取电触点） | 拓普赛 | 💰 ¥19 |
| **半双工转接板 + UBEC**（顶掉 HAT 的总线+配电功能） | 飞特/灵影转接板 + 现成 UBEC | 💰 ¥47 |
| `imu_to_dxl` 打样（2 层）+ 元件 | 嘉立创 + 立创（BOM 见[设计包](docs/imu_to_dxl-设计包/BOM.md)） | 💰 ¥55–100 |
| USB 调试板 FE-URT-1（舵机到货先测总线） | 飞特官方店 | 💰 ¥45 |
| 舵机连接线 5264-3P 多长度 | 松甲 | 💰 ~¥10 |
| **电子小计** | | **≈ ¥570** |

### 机械

| 项 | 渠道 | 价格 |
|---|---|---|
| 轴承 14 个（Ø22×16×4 ×11、Ø15×10×3 ×3） | 鑫燚轴承（一个链接买齐两种） | 💰 ~¥40 |
| 螺丝套装 600pcs M2 含（信邦）+ 热熔螺母 ¥22 + 压头 ¥13 + 乐泰243 ¥19 | 见机械清单 | 💰 ~¥81 |
| 耗材 PLA+ 1kg + TPU 500g（全机实际用量 PLA 299g + TPU 26g，逐件体积加权实测） | eSUN/Polymaker/创想 | 💰 ¥140–230 |
| **机械小计** | | **≈ ¥260–350** |

### 舵机（成本核心，占 75%+）

| 渠道 | 15 个合计 |
|---|---|
| **Robotis 国际站**（$23.90/个）⭐ 推荐 | 💰 **≈ ¥2580** |
| Robotis 美国站（$27.49） | ≈ ¥2970 |
| 欧洲含税 | ¥4700+（别） |

## 四、总成本

| 方案 | 合计 | 说明 |
|---|---|---|
| **最低保效果**（无 HAT/无音频，国际渠道舵机） | **≈ ¥3500** | 下表详述 |
| 忠实复刻（打 HAT：4 层 + SMT 数百元起 + 喇叭） | ≈ ¥3900–4500 | SMT 有起订量，波动大 |
| 官方整机 | ≈ ¥2900（$399） | 2026 圣诞发售 |

**为什么自制比买贵还值得做**：差价 ≈ ¥600–1500，买到的是「RL 训练 → 打印 → 画板 → 联调」全流程学习 + 可二次改造的身体 + 公众号系列的全部素材。这笔账在之前的咨询里算过：大头的 90% 学习价值花在测试片和 PCB 的小钱上，舵机钱是"摸到真机"的门票。

## 五、打印方式对比：K1C 自打 vs 嘉立创代打 ⭐

> 精确用量（按打印件体积逐件加权实测）：**PLA 299 g + TPU 26 g**。

| 维度 | K1C 自打 | 嘉立创代打 | 淘宝按重代打 |
|---|---|---|---|
| 花费 | 耗材整卷 ¥160–210（用掉约 1/3，有效成本 ¥80–120）+ 2–3 个晚上 | **实报 ¥266**（全机，2026-09-06 询价） | **实报 ¥99 白色**（按重计价 ≈0.33 元/g，2026-09-06 询价；TPU 件另计约 ¥30） |
| 时间 | 调机 + 打印 2–3 晚 + 失败重打风险 | 上传 → 3–5 天到货 | 3–7 天 |
| 质量一致性 | 取决于调机水平 | 工业机最稳，分袋包装好 | 看店，需自查工艺 |
| 学习价值 | 定标→补偿→实测数据是复刻闭环与公众号素材 | 零 | 零 |

**¥99 店下单前必核四项**：① FDM PLA 还是光固化树脂（树脂脆，结构件否决）；② 报价是 30 种还是 **41 件**（9 种要打多份）；③ 攻丝/轴承座部位壁数 ≥3、填充 ≥40%（备注写明）；④ TPU 两件做不做。另要求**按文件名分袋贴标**（左右镜像件混装是灾难）。
**TPU 被拒的后果（2026-09-06 实况：¥99 店只做 PLA）**：软下巴/软嘴用 PLA 顶的损失 = 叼取技能退化（鸭嘴实为软夹爪）+ 连杆公差无弹性吸收易卡 + 摔机冲击直传舵机；**不影响走路/装配/发声**（嘴不在策略动作空间）。处置：两件（共 26g）单独找 TPU 渠道补打约 ¥30–50（嘉立创起步 22.5 元），不在关键路径（第 3 周才装头部）；或将 PLA 版记为已知偏差先用。**勿让店家降填充冒充软料**——连杆座和螺纹孔会打虚。
**下单纪律**：先只下 [测试片](../print/测试片/README.md)（¥5–10）实测孔径公差，±0.2mm 内再放全机单；公差件（轴承座）可留嘉立创、外壳给便宜店。

**判定**：

- **还没买打印机 → 代打完胜**：¥85–210 vs 买 K1C 的 ¥2500+。**别为一只鸭子买打印机。**
- **已有 K1C → 钱上基本打平**，决策看你要什么：要省时间省心 → 代打；要学习闭环和素材（测试片定标、首件试装的踩坑记录）→ 自打。推荐**混合**：测试片 + 腿部全套自打（定标 + 验证工艺），大件外壳嫌占时间可代打。
- **代打的纪律**：先下小单（测试片 + 腿部 ≈ ¥30–50）试装，确认孔位公差没问题再补全机——41 件一次下单，翻车没人赔。
- 嘉立创可把 `imu_to_dxl` PCB 与打印件**同平台下单**，邮费合并。

## 六、下单链接速查

> 全部备选店铺与避坑说明：[电控采购清单](电控采购清单.md) · [机械采购清单](机械采购清单.md)。价格快照 2026-09-04，下单前复核。

**电子**

| 项 | 价格 | 链接 |
|---|---|---|
| 主控 Radxa Zero 3W 2G/16G | ¥237 | [ALLNET China（官方分销）](https://shop.allnetchina.cn/products/copy-of-radxa-zero-3w)；备选 [mcuzone](https://item.taobao.com/item.htm?id=1055301489376) |
| 散热片 | ¥19.99 | [taobao 788387010174](https://item.taobao.com/item.htm?id=788387010174) |
| 摄像头 IMX219 | ¥32.8 | [tmall 775872575316](https://detail.tmall.com/item.htm?id=775872575316) |
| CSI 排线 15→22pin 4cm | ¥1.88 | [taobao 654755002992](https://item.taobao.com/item.htm?id=654755002992) |
| ToF VL53L8CX | ¥70 | [taobao 1025775539663](https://item.taobao.com/item.htm?id=1025775539663) |
| NP-F550 电池 | ¥52.8 首单 | 淘宝搜「唯卓仕 NP-F550」 |
| NP-F 电池仓 / 供电扣板 | ¥17.8 / ¥19 | [tmall 658975825526](https://detail.tmall.com/item.htm?id=658975825526) / [tmall 926961598924](https://detail.tmall.com/item.htm?id=926961598924) |
| 总线转接板（顶 HAT） | ¥22–26 | [taobao 1005305041207](https://item.taobao.com/item.htm?id=1005305041207) / [983866781632](https://item.taobao.com/item.htm?id=983866781632)；UBEC 搜「UBEC 5V 3A」约 ¥25（估） |
| 舵机连接线 5264-3P | ¥2/条 | [taobao 587191439333](https://item.taobao.com/item.htm?id=587191439333) |
| USB 调试板 FE-URT-1 | ¥45 | [taobao 603181554943](https://item.taobao.com/item.htm?id=603181554943) |
| **舵机 XL330-M288-T ×15** | ≈¥2580 起 | 首选 [robotis.com](https://www.robotis.com) 国际站（$23.90/个，韩国发 1–3 周，落地估 ¥2700–2900 含运费）；求快可询淘宝「韩国官方授权」店（¥198–238/个，现货，下单前向官网核对授权）；或问国内服务商[智能佳 rosrobot.cn](https://www.rosrobot.cn) 15 只批量价。**避坑**：¥430+/个的店溢价近倍；¥95 的「LEAPHand 关节组件」不是 XL330；认准 **M288-T**（勿买高速版 M077-T） |
| `imu_to_dxl` PCB 打样 | ¥25–40 | [jlc.com](https://www.jlc.com)（Gerber 自[设计包](imu_to_dxl-设计包/设计规格.md)画板后导出；元件立创商城按 [BOM](imu_to_dxl-设计包/BOM.md)） |
| HAT 板（可选） | 打样数百元起 | Gerber：[elec_RPI_Robot_HAT](https://github.com/pollen-robotics/elec_RPI_Robot_HAT) `production/` |

**机械**

| 项 | 价格 | 链接 |
|---|---|---|
| 轴承两种规格一链接买齐 | ¥5/个 | [taobao 670727787832](https://item.taobao.com/item.htm?id=670727787832) |
| 螺丝套装 600pcs 含 M2 | ¥26.8 | [taobao 842110292995](https://item.taobao.com/item.htm?id=842110292995) |
| 热熔螺母 M2/M3 400pcs | ¥22 | [taobao 1000673642588](https://item.taobao.com/item.htm?id=1000673642588) |
| 热熔螺母压头 | ¥13 | [taobao 902798112263](https://item.taobao.com/item.htm?id=902798112263) |
| 乐泰 243（认准官方店） | ¥19.11 | [tmall 653848839737](https://detail.tmall.com/item.htm?id=653848839737) |
| 3D 打印代打（替代自打） | **实报 ¥99**（按重店）/ ¥266（嘉立创） | [jlc-3dp.cn](https://www.jlc-3dp.cn/)；淘宝按重店以实际询价为准 |

## 七、能不能换方案？要改什么？

| 方案 | 省多少 | 要改什么 | 判定 |
|---|---|---|---|
| **省掉 HAT**（不要录音/喇叭） | -¥300~600 | ToF 直挂 i2c3，转接板+UBEC 顶总线配电 | ✅ **首推**，效果无损（音频是唯一牺牲） |
| 换飞特 STS3215（便宜 5–10 倍） | 舵机省 ~¥2000 | **官方 9 个 ONNX 全废**、执行器建模/MJCF 惯量/供电全重做、壳子塞不下（55–60g×15） | ❌ 等于做 Open Duck Mini v2，别硬改 |
| 换宇树 S288 | 待实测 | 3S 供电重做、IMU 挪 SPI（正好配合[设计包]改）、力矩标注存疑待验证 | ⚠️ 先买 1 只实测再说 |
| 买 OpenMicroDuck 社区版 | 看他们定价 | —— | 👀 盯本月 M1 里程碑（整机装配+行走验证） |

## 八、最低成本路径（保效果前提下）

1. **保 XL330** —— 官方 ONNX 直接可用，省下的是几个月重训时间和 GPU 成本，比舵机差价大得多；
2. **省 HAT**（-¥300~600）：无音频代价；
3. **主控走 ALLNET**（¥237 vs 淘宝 ¥690+）；
4. **元件走立创基础库**（HT7533 等免上料费，见 BOM 注）；
5. **PCB 只打 `imu_to_dxl` 一块**（¥25–40）；
6. 螺丝/热熔螺母买套装不散买。

→ **地板价 ≈ ¥3400–3600**。再往下砍只剩换舵机一条路，而它砍的是钱、断的是"开机即走"——不推荐第一台就做。
打印部分：已有打印机则自打（省的是代打费，花的是晚上）；没有打印机**务必代打**（¥85–210），
千万不要为这只鸭子新购打印机——那会把地板价直接抬高一倍。

## 九、全方位复刻路线

- **30 天硬件排期**：[复刻关键路径-30天.md](复刻关键路径-30天.md)（打印/电路/采购/软件四条依赖链）
- **RL 训练与公众号线**：`rl-series/30天计划.md`（12 篇文章 + 实验闭环）
- **每周交汇**：硬件里程碑 = 公众号文章素材；训练实验 = 真机部署的备份方案

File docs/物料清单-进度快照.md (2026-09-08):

# 物料清单 · 进度快照（2026-09-07）

> 回答：「买了舵机、Zero 3W、打完外壳，还差哪些？」
> 本页是**带进度标记的最新清单**；价格依据与店铺实链见[复刻总清单](复刻总清单.md)§6（快照 2026-09-04/06）。
> 标记：✅ 已到手 ｜ 🟡 已购/待确认 ｜ ⬜ 待购 ｜ 🔧 待动手（不花钱）

## 一、进度总览（2026-09-07 更新：舵机为**飞特 HL-1910-C001 ×15，¥1500**——换舵机路线正式激活）

| 大项 | 状态 |
|---|---|
| 舵机 **飞特 HL-1910-C001 ×15（¥1500）** | 🟡 已购。**HLS 恒力系列 TTL 串行总线舵机**（磁编码、电流环）——非 Dynamixel！影响面见下节 |
| 主控 Radxa Zero 3W（¥299） | ✅ 已购（官方路线零移植） |
| 外壳打印件 41 件（¥99） | ✅ 已到手（按 **XL330 舵机仓**设计——** HL 尺寸是否装得进 = 头号验证项**，见下） |
| 本地仿真链路 | ✅ 跑通；expC 2199 迭代 checkpoint 可作"换执行器退化基线" |

## 一⁺、飞特路线的四层影响（照 [换舵机重训全流程](换舵机重训全流程.md) 执行）

| 层 | 影响 | 行动 |
|---|---|---|
| ① 几何 | ⚠️ **头号风险**：打印件舵机仓按 XL330（20×34×26mm）设计，HL 尺寸/孔位大概率不同 | 到货先量尺寸：装不进 → 打"转接适配板"（小件补打）或局部重画舵机仓 |
| ② 电气 | HL 系列 7.4V 级 → 与 2S 电池匹配（比 XL330 超压更规范✅）；堵转电流待实测 | 到货实测堵转电流 → 校 UBEC/转接板预算 |
| ③ 通信 | 飞特 TTL 协议（**非 Dynamixel V2**）；HL 恒力系列带电流环、协议可能是 SCS/STS 扩展 | G2 门控改为：FE-URT-1（飞特自家调试板，正对口）+ rustypot feetech 模块跑通单只；`imu_to_dxl` 固件走**飞特协议分支**（设计包已预留，硬件不变）；Rust 运行时 `bus.rs` 需适配层（参考 Open Duck Mini 的 rustypot 用法） |
| ④ 动力学 | **官方 9 个 ONNX 全部作废，必须重训**（换舵机重训全流程 §4）；HL 电流环是升级项（可做力矩限制） | 到货先做单舵机台架辨识（§2：PD 阶跃/堵转曲线/回差/摩擦/armature）→ 填 BAM 参数 → 按优先级重训（先 Velocity 走路） |

> 💰 **财务面**：舵机 ¥1500 vs XL330 方案 ¥2580+，**省约 ¥1100**。已花 ¥1898（舵机+主控+外壳），
> 加剩余 ≈¥560，整机预计 **≈¥2460**——低于官方整机 ¥2900。代价 = 重训工作量（GPU 或 `--hf-jobs`）。

## 二、还差的（规格导向采购单：按"搜索词 + 验收规格"买，链接价格会漂移，规格不会）

> **舵机连接线买多长？** 官方无线束图纸（已知空白），按鸭子几何估算：
> 躯干到左右髋起点 ≈ 10–20cm；腿内相邻舵机一跳 ≈ 5–10cm；颈链 3 只总长 ≈ 10–20cm。
> **结论：10cm ×5 + 15cm ×5 + 20cm ×5 混合装（共 15 条），30cm 以上不要**（盒内盘线+扎带解决余量）。
> ⚠️ **但连接线建议等 HL-1910 到货当天再下单**：先确认它出线插头是 **5264-2.5mm** 还是
> XH2.54/PH2.0——插头不对，买回来的线就用不上。舵机包装盒通常自带 1 条短线，先拆开看。

### 第一批 · 本周（解锁 G1/G2，≈¥180）

| 项 | 搜索词 | 验收规格（买前逐条核对） | 数量 | 约价 |
|---|---|---|---|---|
| 飞特调试板 | 淘宝「飞特 FE-URT-1」 | 飞特官方店；支持 STS/SCS/**HLS 系列** TTL；1Mbps | 1 | ¥45 |
| ~~舵机连接线~~ | **等舵机到货再买** | 3P 5264-2.5mm（以到货实插为准），**10/15/20cm 各 5 条**，26AWG+ | 15 | ~¥15 |
| 轴承 | 淘宝「轴承 **16x22x4** 薄壁」+「轴承 **10x15x3**」 | 深沟球，外22×内16×宽4（薄壁，ZZ 金属防尘盖或 2RS 均可）×11；外15×内10×宽3 ×3；公差 P0 足够 | 11+3 | ~¥40 |
| M2 螺丝 | 淘宝「**M2 内六角螺钉 DIN912** 304不锈钢 组合装」 | **必须含 M2**（很多套装最小只到 M3，看清 SKU）；规格覆盖 ×4/×6/×8/×12；另配 M2 螺母 ≥50 | 600pcs 盒 | ¥23–27 |
| 热熔螺母 | 淘宝「**M2 热熔螺母 铜嵌件 滚花**」 | 铜、双通道滚花、**M2×外径~4.6×长~4.8mm**（买 M2+M3 混装更划算） | ≥60（买 400pcs 装） | ¥22 |
| 压头 | 淘宝「热熔螺母 **压头 M2** 936/T12」 | 与你烙铁的发热芯型号匹配 | 1 套 | ¥13 |
| 乐泰 243 | 天猫「**乐泰 243**」 | 汉高官方店；中强度可拆卸；10ml | 1 | ¥19 |
| TPU 两件代打 | [jlc-3dp.cn](https://www.jlc-3dp.cn/) 上传 STL | 材料 **TPU 95A**、填充 ≥30%、壁 ≥3 圈；文件：`print/打印件/` 的 `jaw_soft_软下巴.stl` + `soft_mouth_top_软嘴顶部.stl`（共 26g） | 2 | ¥30–50 |

### 第二批 · 与第一批并行（电子，≈¥280）

| 项 | 搜索词 | 验收规格 | 数量 | 约价 |
|---|---|---|---|---|
| 电池 | 淘宝「**唯卓仕 NP-F550**」 | **NP-F550/F570 规格**（38.4×20.6×70.8mm，⚠️F970 装不进）；7.4V 2S；≥2200mAh；带 Type-C/micro 充电口 | 1 | ¥53 |
| 供电扣板 | 淘宝「**NP-F 电池扣板 Type-C**」 | NP-F 卡口、**输出为电池原电压 7.4V 直出**（裸线或 DC5521，别买只出 5V 的） | 1 | ¥19 |
| 总线转接板 | 淘宝「飞特 **TTL 总线舵机驱动板**」 | 飞特 ST/SC/**HLS** 通用；UART(TX/RX)→半双工 TTL；**确认支持 1Mbps** | 1 | ¥22–26 |
| UBEC | 淘宝「**UBEC 5V 3A**」 | 输入覆盖 2S（6–8.4V）降压输出 5V≥3A；线性稳压器不行（压差不够） | 1 | ~¥25 |
| 摄像头 | 淘宝「**IMX219 摄像头 树莓派**」 | 传感器必须是 **IMX219**（800 万，非 OV5647）；接口 **15pin 1.0mm 排针座**版 | 1 | ¥33 |
| CSI 排线 | 淘宝「**15pin 转 22pin CSI 排线**」 | **15P 1.0mm → 22P 0.5mm**，金手指对插；长度 **4–15cm**（买最短） | 1 | ¥2–5 |
| ToF | 淘宝「**VL53L8CX 模组**」 | 型号**逐字核对**：VL53L8CX（VL53L5CX 也可，固件自动识别）；**8×8 多区**；带 Qwiic/JST-SH 4P 接口；⚠️ VL53L0X（单点）和 VL53L7CX（90° 视场）都不认 | 1 | ¥70–80 |

### 第三批 · 自制板（≈¥55–100，含 1 天画图）

| 项 | 状态 |
|---|---|
| `imu_to_dxl` 原理图/PCB | 🔧 **唯一要画的**：连接表已备（`docs/imu_to_dxl-设计包/原理图连接表.md`），立创 EDA 照表连 → 打样参数：**2 层 / 1.6mm / HASL / 5 片**，[jlc.com](https://www.jlc.com) ¥25–40 |
| 元件 14 种 | 立创按 [BOM](imu_to_dxl-设计包/BOM.md) 编号下单 ¥30–60；**特别核对：C6 输入电容 10µF ≥25V 0805 X7R**（挂 8.4V 总线，10V 件会超压）；HL 路线下固件走**飞特协议分支**（硬件不变） |

### 可选 / 暂缓

| 项 | 说明 |
|---|---|
| HAT 板打样 + SMT | 数百元起；**默认不做**（转接板+UBEC 已顶掉其必需功能，牺牲的只是录音/喇叭） |
| 喇叭 5W | 同上，跟随 HAT 决策 |
| 轮滑变体 15 件 | 玩乐功能，最后再说 |
| 备用：测试片补打 | 若 41 件实测有批量性孔径问题，回去补定标 |

## 三、合计与支出曲线

```
已花：飞特舵机 ¥1500 + Zero 3W ¥299 + 外壳 ¥99 = ¥1898（大头已出）
还差：第一批 ¥180 + 第二批 ¥280 + 第三批 ¥100 ≈ ¥560（±50）
预计：整机到手总成本 ≈ ¥2460 —— 低于官方整机 ¥2900 ✓
新增（换舵机代价）：重训算力 —— 9 个技能 × GPU 训练（或 --hf-jobs），另计
```

## 四、到手后立刻做的三件动手事（不花钱）

1. **收货实测（G1）**：M2 螺丝逐件试穿 41 件孔位、轴承到手试压座、数据回填[构建日志](../构建日志.md)验证表；
2. **单舵机验总线（G2）**：FE-URT-1 接第一只 HL-1910 → 飞特协议 PING → 读写位置 → 1Mbps 跑 10 分钟；**同时量尺寸/重量/堵转电流/回差**（重训辨识数据一并采集，见[换舵机重训全流程](换舵机重训全流程.md) §2）；其余 14 只逐只过一遍再装（装上前 15 分钟，省去装后拆机的 15 小时）；
3. **Zero 3W 刷机**（可与 1/2 并行）：Armbian + `deploy/` 流程，过三坑（mask serial-getty、i2c3/FUSB302 取舍、NPU overlay）。

*相关：采购实链 [复刻总清单](复刻总清单.md) · 阶梯门控 [阶梯式采购与验证路线](阶梯式采购与验证路线.md) · 换舵机判定 [换舵机重训全流程](换舵机重训全流程.md)*

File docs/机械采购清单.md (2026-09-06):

# 机械采购清单（国内 / 淘宝）

> **快照时间：2026-09-04。** 价格与销量会变，链接可能失效，下单前自己核价。
> 电子电气件（主控 / 摄像头 / ToF / 电源 / PCB / 线材）见 [电控采购清单](电控采购清单.md)。
>
> 数量来自 MJCF `robot_walk.xml` 的 mesh 实例计数与孔特征反推，**是推导值不是官方图纸**。

---

## 一、轴承（共 14 个，两种规格）

数量直接数 `robot_walk.xml` 里的 mesh 引用，六个 MJCF 变体计数完全一致。
**规格是实测网格几何得出的，不是看文件名**：

| 规格 | 数量 | 实测（外径 / 内孔 / 宽） | 网格 |
|---|---|---|---|
| **Ø22 × 16 × 4** | **11** | 22.0 / **16.0** / 4.0 mm | `seeed_bearing__configuration__22x16x4` |
| **Ø15 × 10 × 3** | **3** | 15.0 / **10.0** / 3.0 mm | `seeed_bearing__configuration_default` |

| 店铺 | 说明 | 价格 | 链接 |
|---|---|---|---|
| **NBZH 永天轴承**（16年老店） | 不锈钢超薄壁 `ET2216ZZ` / `MR16224` / `SET2216` / `DDA2216`，16×22×4 | **¥2.2** | [taobao 539024647147](https://item.taobao.com/item.htm?id=539024647147) |
| **鑫燚轴承**（7年老店） | NSK 微型轴承，**同一链接同时有 10×15×3 和 16×22×4** | **¥5** | [taobao 670727787832](https://item.taobao.com/item.htm?id=670727787832) |

> 💡 鑫燚那条一个链接能把两种规格一起买齐，省事。

> ⚠️ **`bearing_roll` 不是轴承，也不是采购件。** MJCF 里还有一个出现 2 次的网格叫
> `bearing_roll`，实测是 **23 × 3 × 40 mm、带 Ø≈18 中心孔的平板**（体积 625 mm³，填充率 23%），
> 且与 `trunk_base` / `yaw2roll` / 外壳出自**同一个 Onshape Part Studio**
> （elementId `d6fcdccc8b25aaa256e7e213`），而两颗真轴承在另一个带配置串的标准件库里。
> 它是 hip_roll 轴那颗 Ø22 轴承的**压盖**，**要打印，不用买**。见 [打印件](#四打印件)。

---

## 二、紧固件（M2 系统，约 325 件）

整机 M2 级孔（Ø1.9–2.5 mm、包角 ≥300°）**按装配体用量加权共 237 个**：
60 个在舵机本体上（15 × 4）、21 个在轴承/PCB/电池等标准件上、结构件上约 156 个。
下面按 325 件给，对 237 个孔位有 **1.37×** 余量。

| 规格 | 建议数量 | 用途 |
|---|---|---|
| M2×4 内六角圆柱头 | 60 | 薄壁位 |
| **M2×6 内六角圆柱头** | **80**（主力） | |
| M2×8 内六角圆柱头 | 40 | 孔深 3–5 mm |
| M2×12 内六角圆柱头 | 15 | 少量深孔 |
| M2 螺母 | 50 | 无攻丝处 |
| **M2 热熔螺母** | **60** | 打印件推荐，比直接攻丝牢得多 |
| M2.5×6 | 20 | 少量 Ø2.7 孔位 |

推导过程见 [紧固件反推](紧固件反推.md)。

### 螺丝套装

| 店铺 | 说明 | 价格 | 销量 | 链接 |
|---|---|---|---|---|
| **广州信邦电子**（10年老店，包邮） | **600 pcs** 盒装不锈钢 沉/平头内六角 **M2/M2.5/M3** 组合，**送扳手** | **¥26.8** | 42 | [taobao 842110292995](https://item.taobao.com/item.htm?id=842110292995) |
| 宏顺通五金工厂店（8年老店） | 600 pcs M2/M2.5/M3 沉头内六角 + 螺母 + 送工具 | ¥23 | 2 | [taobao 842400332284](https://item.taobao.com/item.htm?id=842400332284) |
| 广州信邦电子（10年老店，包邮） | 304 不锈钢 M2–M8 盘头内六角 + 螺母 + 垫片套装 | ¥19.8 | 71 | [taobao 888186264852](https://item.taobao.com/item.htm?id=888186264852) |

> 💡 **优先选写明含 M2 的套装。** 很多「M2M3M4M5M6M8 大全」标题里带 M2，实际最小只到 M3 ——
> 下单前看清 SKU。本项目 **M2 是绝对主力**，M3 基本用不上。

### 热熔螺母 + 压头

| 店铺 | 说明 | 价格 | 销量 | 链接 |
|---|---|---|---|---|
| **深圳市榕誉微电子**（6年老店） | **400 PCS M2 + M3** 热熔铜螺母，双通道滚花 | **¥22** | 200+ | [taobao 1000673642588](https://item.taobao.com/item.htm?id=1000673642588) |
| 深圳市榕誉微电子（6年老店） | 80/220 PCS M2–M6 热熔铜螺母 | ¥18 | 1000+ | [taobao 922318148975](https://item.taobao.com/item.htm?id=922318148975) |
| 天卓五金官方旗舰店（包邮） | 土八热熔螺母 M1–M8，按规格散买 | ¥0.77 起 | 4万+ | [tmall 809364062256](https://detail.tmall.com/item.htm?id=809364062256) |

> ⚠️ **别忘了压头。** 热熔螺母要用**专用烙铁压头**压入，普通烙铁头压不正、会歪。

| 店铺 | 说明 | 价格 | 销量 | 链接 |
|---|---|---|---|---|
| **烙铁工具**（7年老店） | 3D 热熔螺母压头套件 M2–M8，适用 **936 / T12 / T65** | **¥13** | 800+ | [taobao 902798112263](https://item.taobao.com/item.htm?id=902798112263) |
| 外茂优品（包邮） | 同类 M2–M8 压头套件 | ¥11.5 | 200+ | [taobao 966212633086](https://item.taobao.com/item.htm?id=966212633086) |

### 螺纹胶（金属对金属螺丝位防松）

舵机输出轴、金属件对接处建议上中强度螺纹胶。

| 店铺 | 说明 | 价格 | 销量 | 链接 |
|---|---|---|---|---|
| **LOCTITE 乐泰旗舰店** | 汉高乐泰 **243** 中强度可拆卸螺纹锁固剂 | **¥19.11** | 1万+ | [tmall 653848839737](https://detail.tmall.com/item.htm?id=653848839737) |
| LOCTITE 乐泰企业店 | 243 / 263 螺纹锁固剂 | ¥18.4 | 700+ | [taobao 663963768247](https://item.taobao.com/item.htm?id=663963768247) |
| 工业胶厂家直销（包邮） | 乐泰 243 / 242 / 263 | ¥16.8 | 600+ | [taobao 925965306702](https://item.taobao.com/item.htm?id=925965306702) |

> ⚠️ **低于 ¥15 的要当心。** 搜索结果里有 ¥8、¥10 的「乐泰 243」，正品不会到这个价。
> 认准 LOCTITE 官方店或授权经销商。

---

## 三、耗材

| 材料 | 用量 | 用在哪 |
|---|---|---|
| **PLA / PETG** | 约 300–500 g | 绝大部分结构件 |
| **TPU** | 少量 | `jaw_soft_软下巴`、`soft_mouth_top_软嘴顶部` —— 从命名和用途判断建议软料 |

> 打印工艺与公差评估尚未做，见 [PROGRESS.md](../PROGRESS.md) 风险清单。
> **仿真 STL ≠ 可打印工程件** —— 只保证外形与惯量，没有配合公差、螺纹孔、热熔螺母座。

---
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

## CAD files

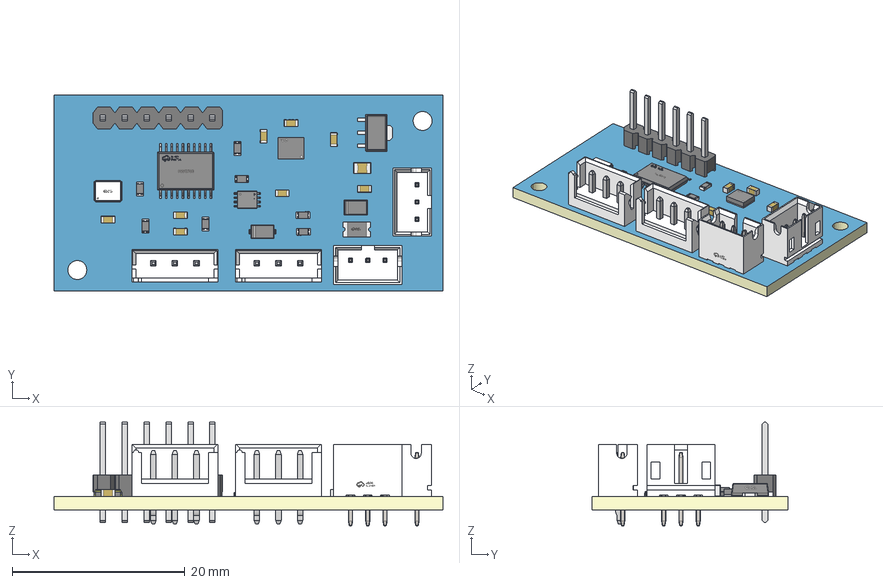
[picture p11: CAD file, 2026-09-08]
hardware/imu_to_dxl/imu_to_dxl-PCB.step
45.1 x 22.7 x 12.0 mm
Board~ss66
TopCopper~ss66
BottomCopper~ss66
TopSilkscreen~ss66
BottomSilkscreen~ss66
TopFpcStiffener~ss66
BottomFpcStiffener~ss66
C0805~C0805_L2.0-W1.3-H1.3~nCY8
SOD-123FL_L2.7-W1.8-LS3.7-RD~SOD-123FL_L2.8-W1.8-H1.1-LS3.6~Ts2a
LGA-14_L3.0-W2.5-P0.50-BR~LGA-14_L3.0-W2.5-P0.50-BR~xgQh
CONN-TH_B3B-EH-A-LF-SN~CONN-TH_B3B-EH-A-LF-SN~hPIn x 2
R0603~R0603~2pOD x 7
HDR-TH_6P-P2.54-V-M~HDR-TH_6P-P2.54-M-LI-1X6P~mF3L
VSSOP-8_L2.3-W2.0-P0.50-LS3.1-BR~VSSOP-8_L2.3-W2.0-P0.50-LS3.1-BL~MIWO
SOD-123_L2.7-W1.6-LS3.7-RD~SOD-123_L2.7-W1.6-H1.4-LS3.7~0OJw
TSSOP-20_L6.5-W4.4-P0.65-LS6.4-BL~TSSOP-20_L6.5-W4.4-H1.0-LS6.4-P0.65~VWKP
C0603~C0603_L1.6-W0.8-H0.8~crEB x 8
CONN-TH_B3B-PH-K-S~CONN-TH_B3B-PH-K-S~Q7be x 2
SOT-89-3_L4.5-W2.5-P1.50-LS4.2-BR~SOT-89-3_L4.3-W2.5-H1.6-LS4.1-P1.50~uLfP
OSC-SMD_4P-L3.2-W2.5-BL_SIT8008BI~OSC-SMD_4P-L3.2-W2.5-H1.0~S9ms
F1206~F1206_L3.2-W1.7-H0.6~vEE0

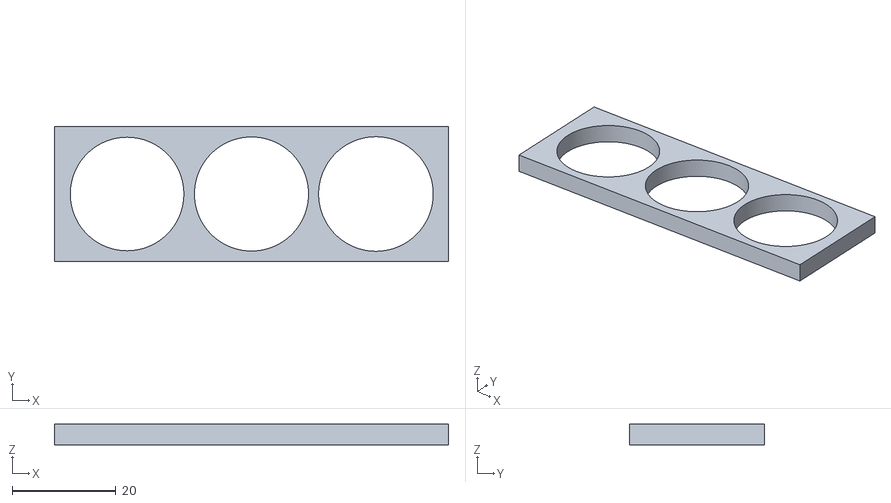
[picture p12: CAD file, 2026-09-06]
print/测试片/测试块-轴承22x16x4压入三档-76x26x4.stl
76.0 x 26.0 x 4.00

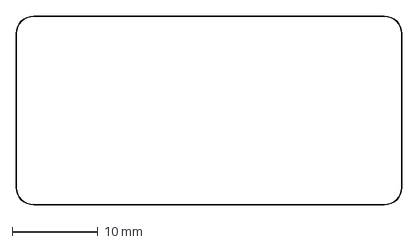
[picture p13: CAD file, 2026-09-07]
hardware/imu_to_dxl/imu_to_dxl-板框-45x22-R2.dxf
45.0 x 22.0 mm

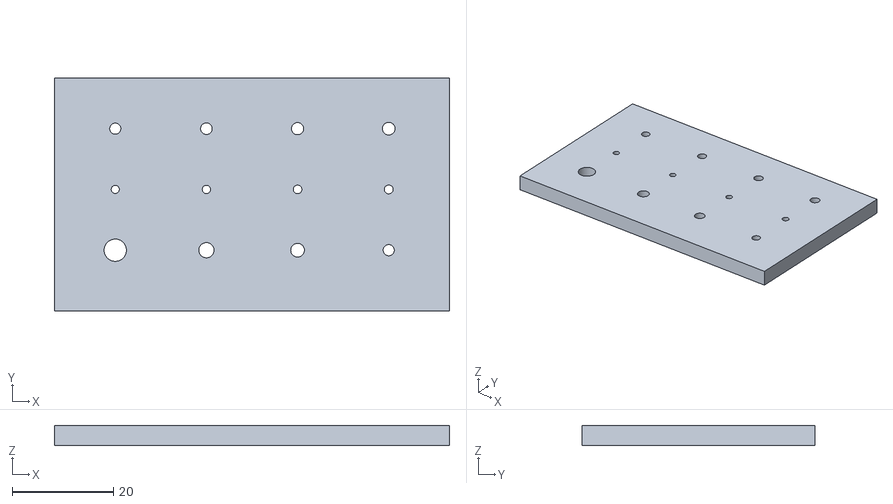
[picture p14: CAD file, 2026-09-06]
print/测试片/测试片-M2孔径阶梯-78x46x4.stl
78.0 x 46.0 x 4.00

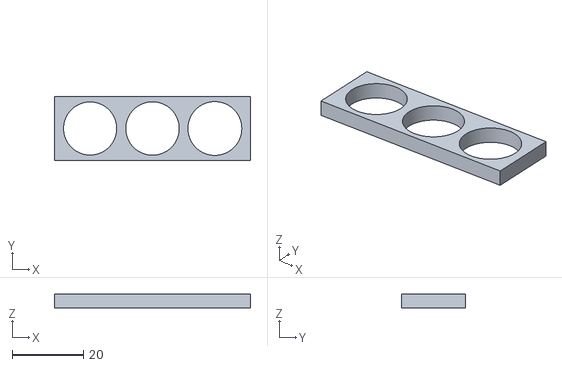
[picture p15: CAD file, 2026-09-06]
print/测试片/测试块-轴承15x10x3压入三档-55x18x4.stl
55.0 x 18.0 x 4.00

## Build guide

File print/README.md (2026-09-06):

# 3D 打印件

> 🛒 耗材、紧固件、热熔螺母与压头的采购链接见 [机械采购清单](../docs/机械采购清单.md)。

**简体中文** · [English](README.en.md)

整机全部 STL，按「**要打印**」和「**买现成的**」分好类，文件名中英双语。

| 目录 | 数量 | 说明 |
|---|---|---|
| [`打印件/`](打印件/) | **30 种 / 41 件** | 步行装配体需要的结构件。**有 9 种要打多份，务必看下面的数量表** |
| [`变体-轮滑/`](变体-轮滑/) | 5 种 / 15 件 | 轮滑功能的替换件，不做轮滑就不用打 |
| [`标准件-无需打印/`](标准件-无需打印/) | 8 | 舵机、轴承、电池、电路板的模型，**仅供对位和干涉检查** |
| [`上游已删除/`](上游已删除/) | 2 | 任何装配体都不引用，上游 2026-09-01 已移除。存档用 |

## ⚠️ 打几个：8 种零件要打多份

数量取自上游 `robot_walk.xml` 的 geom 引用计数，不是估的。

| 零件 | 数量 |
|---|---|
| `leg_腿部` | **×4** |
| `hip_l_髋部左` | ×2 |
| `neck_颈部` | ×2 |
| `power_support_电源支架` | ×2 |
| `sole_left_左脚底` | ×2 |
| `sole_right_右脚底` | ×2 |
| `upper_leg_rigidity_plate_上腿加固板` | ×2 |
| `yaw2roll_偏航转横滚` | ×2 |
| `bearing_roll_横滚轴承压盖` | ×2 |
| 其余 21 种 | 各 ×1 |

**轮滑变体**：`tire_轮胎` **×8**、`rim_轮辋` **×4**、`roller_blade` ×2、`ankle_l_v1`/`ankle_r_v1` 各 ×1。

> ⚠️ 轮滑脚踝比标准脚踝**高 10 mm**（46.5 vs 36.5），两套不能混用。

完整物料清单（含舵机、轴承、螺丝、电子件）见 [`../BOM.md`](../BOM.md)。

## 文件名规则

```
upper_leg_left_左上腿.stl
└──── 上游原名 ────┘└─中文─┘
```

前半段是上游 `microduck_rl` 里的原始文件名，方便和 MJCF、源码对照；后半段是中文，方便直接看懂是什么件。

## 与上游的差异

抓取时上游 `robot/microduck/assets` 有 **47 个 STL**，这里保留 **46 个**。

**去掉的 1 个重复**：右上腿在上游有 `upper_leg_right` 与 `right_upper_leg` 两个文件，
面数（12250）、包围盒、质心完全一致 —— 同一几何体的两次导出，只保留 `upper_leg_right`。

**分类调整**：轮滑专用件移入 `变体-轮滑/`；两个任何 MJCF 都不引用、且上游已删除的躯干壳
移入 `上游已删除/`。

> 上游的 XL330 台架测试夹具（`bench_holder`、`weight`、`spacer`、`axis`、`arm`、`part_1..5`）
> 在另一个目录 `robot/xl330_test_bench/assets`，不属于机器人，本来就不在这 47 个里。

## 打印建议

本仓库暂无官方打印参数（上游没有公开）。已知的实测信息见 [`../构建日志.md`](../构建日志.md)。

几个从结构上能看出来的点：

- **头壳、躯干壳**是外观件，建议层高 0.12–0.16 mm
- **腿部结构件**承力，建议加大壁厚和填充
- **`soft_mouth_top` / `jaw_soft`** 名字带 soft，原版应为软性材料（TPU 类）
- **`tire_轮胎`** 同理，轮滑用的胎，硬材料打出来会打滑
- 打印件上的 M2 孔位建议用**热熔螺母**而不是直接攻丝，螺丝清单见 [`../docs/紧固件反推.md`](../docs/紧固件反推.md)

## 授权

这些 STL 是上游 `pollen-robotics/microduck_rl` 公开发布文件的**衍生作品**（重命名与分类整理），
遵循与上游一致的 **CC BY-NC-SA 4.0**：署名、相同方式共享、非商业使用。

详见 [`../NOTICE.md`](../NOTICE.md)。

---

## 勘误（2026-09-04）

`bearing_roll` 此前被归入 `标准件-无需打印/`（当成买现成的轴承），**这是错的**。判据：

1. **几何** —— 实测 **23 × 3 × 40 mm**、带 Ø≈18 mm 中心孔的平板，体积 625 mm³（填充率 23%）。
   没有任何标准轴承是这个形状；两颗真轴承实测是 22.0/**16.0**/4.0 与 15.0/**10.0**/3.0 的回转体。
2. **出处** —— `assets/*.part` 的 Onshape `elementId`：`bearing_roll` 与 `trunk_base`、`yaw2roll`、
   `left_shell`、`right_shell`、`power_support`、`neck` 同属 `d6fcdccc8b25aaa256e7e213`
   （自建打印件的躯干 Part Studio）；两颗真轴承在 `92eaf48a756ec816309fc756`，
   带配置串 `..._22x16x4` / `..._Default`，是典型标准件配置库。
3. **装配** —— 它与 `yaw2roll` 在同一个 body、同一个 `pos`，quat 只差整体符号（同一旋转），
   是贴在 yaw2roll 侧面、往下多伸 19.5 mm 的一块盖板 —— 功能上是 hip_roll 轴那颗
   Ø22 轴承的**压盖/挡板**（Ø18 孔小于 Ø22 外径，正好挡住外圈）。

原中译「轴承滚轮」也错了 —— 既不是轴承也不是滚轮，已改为「横滚轴承压盖」。
打印件计数因此 **29 种 / 39 件 → 30 种 / 41 件**，标准件 **9 → 8**。

> 另注：`robot_walk.xml:264` 里右腿 hip_yaw 那个 link 被 onshape-to-robot 命名成
> `<body name="bearing_roll">`，但它内部的可视件是 `yaw2roll_2` —— 这只是链接命名巧合，
> 与零件性质无关。

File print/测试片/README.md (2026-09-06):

# 测试片图例（先打这个！）

> 复刻全机 237 个 M2 孔位和 14 个轴承座之前，先用这 3 个小件定标**你这台打印机**的实际公差。
> 总打印时间约 40 分钟，耗材约 15g。生成脚本：`scripts/generate_test_coupon.py`（尺寸可改后重新生成）。

## 1. `测试片-M2孔径阶梯-78x46x4.stl`

三行孔，每行从左到右 4 个（x = 12 / 30 / 48 / 66 mm）：

| 行（y 坐标） | 从左到右 | 判定方法 |
|---|---|---|
| 上行 y=36 | **M2 过孔阶梯 Ø2.2 / Ø2.3 / Ø2.4 / Ø2.5** | M2 螺丝手指能顺畅穿过、不晃 → 最小的那个就是你机器的过孔补偿值 |
| 中行 y=24 | **攻丝底孔阶梯 Ø1.60 / 1.65 / 1.70 / 1.75** | M2 自攻拧入 ≥3 圈不裂不旷 → 那个值就是攻丝底孔补偿 |
| 下行 y=12 | 参考 Ø4.4（沉头径）/ Ø3.0 / Ø2.7（M2.5 底孔）/ Ø2.2 | 对照用 |

## 2. `测试块-轴承22x16x4压入三档-76x26x4.stl`

Ø21.9 / Ø22.0 / Ø22.1 三孔（左→右）。把 **22×16×4 轴承**（11 个/机）逐个试压：

- **轻压入、拔不出来** = 过盈档 ✓（理想）
- 手指能压进去也抠出来 = 间隙档（太松，点胶固定用）
- 压进去开裂 = 过盈过头

## 3. `测试块-轴承15x10x3压入三档-55x18x4.stl`

Ø14.9 / Ø15.0 / Ø15.1 三孔，试 **15×10×3 轴承**（3 个/机），判定同上。

## 打印参数（就这次，别用高速）

PLA、0.2mm 层高、100% 填充、壁 3 圈、**速度 ≤100mm/s**、关闭"水平孔补偿"先打一版原始值。

## 测完之后

把两个"刚好"值填进 [构建日志](../构建日志.md) 的「尺寸与配合验证」表，
然后按 [打印工艺调整表](../docs/打印工艺调整表.md) 的补偿建议设置切片器，再开始批量打印。

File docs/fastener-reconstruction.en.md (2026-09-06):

# Fastener Reconstruction

> ⚠️ **This English version lags behind the Chinese original.** Several corrections (camera rotation, MK1 part number, U10 placement, STS3032 torque basis, board SKU) were applied to the Chinese docs first. **When the two disagree, the Chinese version wins.** Last sync: 2026-09-05.

[简体中文](紧固件反推.md) · **English**

There is no mechanical BOM upstream and no screw list (the HAT board has an electronics BOM, but it covers no structural parts). Everything below was **recovered from the
geometry of the 47 STL meshes.**

## Method

`scripts/analyze_holes.py`:

1. Weld duplicate vertices, build a face-adjacency graph
2. Cut at a 35° dihedral angle and region-grow "smooth surface patches" (breaks at sharp
   edges)
3. Fit a cylinder to each patch — a cylinder's face normals are all perpendicular to its
   axis, so **the axis is the smallest eigenvector of the normal covariance matrix**
4. Project the vertices onto the plane perpendicular to that axis and fit a circle
   (Kåsa algebraic fit) for the diameter; discard anything with >3 % relative residual
5. Normals pointing toward the axis = **a hole**; pointing away = a shaft or boss, excluded
6. Measure angular coverage and keep only complete circles (≥300°)

All 47 parts scan in 2.5 seconds.

## Conclusion: The Whole Robot Is an M2 System

Diameter distribution of complete circular holes across the structural parts:

| Diameter | Count | Reading |
|---|---|---|
| **Ø2.2** | **77** | **M2 clearance hole** (standard M2 clearance is 2.2–2.4) |
| **Ø4.4** | **28** | **M2 counterbore** (M2 socket-head cap dia. is Ø3.8; counterbore 4.0–4.5) |
| **Ø1.6** | **20** | **M2 tapping hole** (the standard M2 tap drill is exactly 1.6) |
| Ø2.4 | 22 | loose M2 clearance |
| Ø2.0 | 12 | tight M2 clearance |
| Ø2.7 / Ø2.8 | 20 | M2.5 clearance (a small number) |
| Ø4.8 | 10 | M2 counterbore, a second depth |
| Ø5.4 / Ø6.0 | 16 | shaft bores / bearing seats — not fasteners |

**Ø2.2 and Ø4.4 appear as a pair** on `yaw2roll`, `leg`, `ankle_left`, `neck_pitch` and
`yaw_roll_motion` — the classic **clearance hole + counterbore** combination, which
confirms **M2 socket-head cap screws**.

Cross-check: `xl330.stl` itself carries **4× Ø2.0 + 8× Ø1.6**, matching the Dynamixel
XL330's own M2 mounting pattern.

## Per-Part Hole Counts

Weighted by how many times each mesh is actually used in the full robot:

| Mesh | Uses | M2 clearance | M2 tap | Counterbore |
|---|---|---|---|---|
| `xl330` | **×15** | 4 | 8 | — |
| `hip_l` | ×2 | 9 | — | 6 |
| `yaw2roll` | ×2 | 8 | — | 6 |
| `leg` | ×2 | 6 | — | 6 |
| `neck_pitch` | ×1 | 12 | — | 4 |
| `face_part` | ×1 | 10 | 4 | — |
| `ankle_left` / `ankle_right` | ×1 each | 5 | — | 5 |
| `yaw_roll_motion` | ×1 | 4 | — | 6 |
| `power_support` | ×1 | — | 8 | — |
| `left_shell` / `right_shell` | ×1 each | 7 / 6 | — / 1 | — |
| `bearing_roll` | ×2 | 4 | — | — |
| `neck` | ×2 | 4 | — | — |
| `upper_leg_rigidity_plate` | ×2 | 4 | — | — |
| `jaw` | ×1 | 5 | — | — |
| `trunk_base` | ×1 | 4 | — | — |
| `bottom_head_shell` / `top_head_shell` | ×1 each | 4 / 3 | — | — |
| `m12_lens_holder` | ×1 | 3 | — | — |

> **`xl330` appears 15 times** — the robot has 15 servos, not 14. Fourteen are under policy
> control; the fifteenth drives the beak/jaw through a `passive_*` linkage and never enters
> the action space. This matches the "15 servos" in the official README.

## Purchase Estimate

- M2-class holes (Ø1.9–2.5 mm, ≥300° wrap) across the assembly, **weighted by usage: 237**,
  of which 60 are on the servo bodies (15×4), 21 on bought parts (bearings / PCBs / battery),
  and about 156 on printed structural parts

  > ⚠️ **Correction (2026-09-04)**: earlier versions said "213", which does not reconcile. Two
  > causes: the earlier count was **not weighted by how often each part is used** (`leg` is ×4,
  > `hip_l` and `yaw2roll` are ×2), and it **included meshes no MJCF references**. The diameter
  > and depth tables below are **unweighted** (each STL counted once) — the two cannot be summed.
  themselves (15 × 4)
- Excluding servos and bought-in parts (bearings, PCBs, battery), the structural parts
  account for **roughly 146 clearance holes**

**Suggested quantities** (including losses and trial fitting):

| Spec | Suggested | For |
|---|---|---|
| M2×4 socket head | 60 | thin-wall positions (51 of 79 holes are 0–3 mm deep) |
| M2×6 socket head | 80 | the workhorse size |
| M2×8 socket head | 40 | 3–5 mm deep positions (24 of 79) |
| M2×12 socket head | 15 | a few deep holes (8–12 mm, 4 places) |
| M2 nuts | 50 | where there is nothing to tap into |
| M2 heat-set inserts | 60 | recommended over tapping printed plastic directly |
| M2.5×6 | 20 | the handful of Ø2.7 positions |

Lengths are inferred from the measured depth distribution of the Ø2.2 holes: 51 at
0–3 mm, 24 at 3–5 mm, 4 at 8–12 mm.

## Bearings

| Source file | Measured |
|---|---|
| `seeed_bearing__configuration__22x16x4` | **OD 22 × ID 16 × W 4 mm** |
| `seeed_bearing__configuration_default` | OD 15 × ID ~10 × W 3 mm (×3 in the robot) |

## ⚠️ Limitations

1. **This is recovered from simulation meshes, not from engineering drawings.** Simulation
   meshes only guarantee correct outer shape and inertia — not fit tolerances or complete
   thread detail.
2. **Print shrinkage changes the real hole size.** A Ø2.2 design hole typically comes out
   0.1–0.3 mm undersize on FDM. Print a test piece and check before committing to a build.
3. **Counterbores and clearance holes may be double-counted** (two features of the same
   screw). Screw counts here are based on clearance holes only; counterbores are not
   counted separately.
4. **Features not detected:** non-circular holes (slots, shaped cutouts), partial arcs with
   <300° coverage, and openings larger than Ø14 mm are all outside the statistics.
5. Screw **lengths** are ranges inferred from hole depth, not measured values.

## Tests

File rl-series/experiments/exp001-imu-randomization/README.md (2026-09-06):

# exp001 · IMU 姿态随机化 A/B 对比

> 状态：**✅ 已完成（2026-09-06，本机 CPU 实跑，100 迭代 × 64 环境，A/B 各 4 分钟）**
> 一次只改一个变量：`ENABLE_IMU_ORIENTATION_RANDOMIZATION`（`microduck_velocity_env_cfg.py` L40，随机幅度 6° 见 L84）

## 结果（对比图：`../../assets/exp001-AB对比.png`）

| 指标 @ iter 99 | A（ON） | B（OFF） | 差异 |
|---|---|---|---|
| **Train/mean_reward** | 0.801 | **1.014** | B 末段反超领先 |
| fell_over | ≈2.08 | ≈1.92 | 无显著差 |
| error_vel_xy | 0.031 | 0.033 | 无显著差 |
| error_vel_yaw | 0.194 | 0.195 | 几乎重合 |
| Policy/mean_std | 0.903 | 0.900 | 几乎重合（都在收敛） |

## 判定（对照预注册标准）

- 预注册假设之一（"B 世界更乖，前期涨更快"）**部分成立**：前 85 迭代两线纠缠，末 15 迭代 B 甩开。
- 预注册预案"100 迭代只能得出前期动力学差异"**命中**：速度跟踪误差、摔倒率、探索噪声完全重合——
  说明随机化在 100 迭代内没有显著拖慢学习，reward 差距来自 B 少了一层观测扰动（更容易拿满分）。
- **A 的鲁棒性收益（随机化的真正目的）本实验无法回答**：需要对两个 checkpoint 做扰动测试
  （施加 IMU 旋转看性能衰减曲线）。→ **已于同日完成，见 `记录-exp001b.md`**：
  趋势符合假设（A 最大衰减 -4.6% vs B -6.0%，10° 起 A 反超），但 100 迭代尺度上差异
  （1–2%）在噪声内，不构成统计结论；工具已固化，待长训练复测。
- 结论一句话：**IMU 随机化不拖累收敛速度，代价是训练期 reward 低 ~20%（观测被扰动的直接代价）；
  它买到的鲁棒性要用扰动测试才能看见。**

## 执行记录

完整命令、指标、运行目录：`记录-A.md` / `记录-B.md`。
过程问题与解决：构建日志 `../../../构建日志.md` 2026-09-06 条目（GPU 选择器、wandb 两个启动坑）。

## 假设（预注册存档，跑之前写好的）

- B 组（无随机化）训练前期 `Train/mean_reward` 涨得更快——它面对的世界更「乖」。
- A 组（默认，有随机化）同迭代数下 `fell_over` 下降更慢。
- 50–100 迭代内大概率看不出两者「最终上限」的差别（鲁棒性差异要更长训练 + 扰动测试才显形），所以本实验的结论很可能是「前期动力学差异」——这也是有效结论。

## 变量

| 组 | L40 值 | 含义 |
|---|---|---|
| A | `True`（默认，不打补丁） | 每环境一个随机轴、≤6° 的固定 IMU 旋转（actor 的 gyro/gravity 被旋转，critic 保持真值） |
| B | `False`（应用 `exp001.patch`） | 无 IMU 随机化，其余全部相同 |

## 执行

```bash
# A 组（默认配置，直接跑；路径无关，脚本自己找仓库）
bash rl-series/experiments/exp001-imu-randomization/run_a.sh

# B 组（打一行补丁 → 跑 → 还原）
cd upstream/microduck_rl
git apply ../../rl-series/experiments/exp001-imu-randomization/exp001.patch
bash ../../rl-series/experiments/exp001-imu-randomization/run_b.sh
git checkout -- src/mjlab_microduck/tasks/microduck_velocity_env_cfg.py   # 跑完还原
```

跑完后两组各有一个 `logs/rsl_rl/velocity/<时间戳>_exp001-{a,b}/` 目录。

## 对比出图

```bash
python ../../rl-series/scripts/plot_ab_compare.py \
  --a logs/rsl_rl/velocity/<A时间戳>_exp001-a \
  --b logs/rsl_rl/velocity/<B时间戳>_exp001-b \
  --label-a "IMU随机化=ON(6°)" --label-b "IMU随机化=OFF" \
  --tags Train/mean_reward Episode_Termination/fell_over \
         Metrics/twist/error_vel_xy Metrics/twist/error_vel_yaw Policy/mean_std \
  --out ../../rl-series/assets/exp001-AB对比.png
```

## 判定标准

| 观察 | 结论 |
|---|---|
| B 前期 reward 更高、A 后期反超 | 经典 sim-to-real 教科书结果，假设成立 |
| 两者曲线几乎重合 | 50/100 迭代不足以体现；如实写，迭代数加到 300 再试一次 |
| B 反而更差 | 【推测】不太可能；若出现，检查补丁是否只改了 L40（`git diff` 留证） |

## 记录表

跑完各填一份：`记录-A.md`、`记录-B.md`（按 `../TEMPLATE.md` 格式）。

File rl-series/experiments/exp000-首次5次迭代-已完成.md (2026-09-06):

# exp000 · 首次冒烟：5 迭代 + CPU smoke（已完成）

> 状态标签：**【已验证】**——以下全部数据由脚本从事件文件原样提取（`scripts/extract_tb_metrics.py`），非手抄。

```text
实验名称：exp000 链路冒烟（train → tensorboard → checkpoint → ONNX）
代码 commit：microduck_rl @ 29e887e（2026-09-02, "Merge pull request #30 from peterschade/sim-body-server"）
本地改动：无
修改参数：无（冒烟测试，只缩规模）
我的假设：5 次迭代足够验证链路全通，但不足以让鸭子学会任何东西
训练命令：
  # cpu-smoke（第 0 次试探，8 环境）
  uv run train Mjlab-Velocity-Flat-MicroDuck
  # lesson-01（正式冒烟）
  uv run train Mjlab-Velocity-Flat-MicroDuck --env.scene.num-envs 8 --agent.max_iterations 5
  （注：params/agent.yaml 快照显示 seed=42, num_steps_per_env=24, num_envs=8）
机器与硬件：Mac mini（Apple Silicon），纯 CPU，microduck_rl/.venv（uv sync）
训练时长：三次 lesson-01 运行分布在 00:03–00:23，每次约 10 分钟内
显存占用：-（CPU）
```

## 产物清单（logs/rsl_rl/velocity/）

| 运行 | 产物 |
|---|---|
| `2026-09-04_23-59-23_cpu-smoke` | tfevents ×1 迭代、model_0.pt、cpu-smoke.onnx |
| `2026-09-05_00-23-33_lesson-01`（采用） | tfevents 5 迭代、model_0–4.pt、lesson-01.onnx、params/、git/ |

ONNX 形状（`inspect_onnx.py` 实测）：`INPUT obs [1,61] / OUTPUT actions [1,14]` ✅

## TensorBoard 变化（lesson-01 原值）

| iteration | mean_reward | fell_over | error_vel_xy | error_vel_yaw | mean_std |
|---|---|---|---|---|---|
| 0 | — | 0.000 | 0.000 | 0.000 | 1.001 |
| 1 | -0.061 | 1.375 | 0.024 | 0.137 | 1.000 |
| 2 | 0.007 | 1.000 | 0.032 | 0.135 | 1.000 |
| 3 | 0.090 | 1.000 | 0.035 | 0.153 | 0.999 |
| 4 | 0.095 | 1.000 | 0.028 | 0.172 | 0.999 |

曲线图：`../assets/lesson01-首次5次迭代真实曲线.png`

## 最终结论

- 【已验证】训练、TensorBoard、checkpoint、ONNX 导出四环节全部打通。
- 【已验证】reward 转正但绝对值极小；`fell_over ≈ 1.0`（每集一摔）；`mean_std` 几乎不动（纯探索期）。
- 【已验证】三次 lesson-01 运行指标逐位一致（同 seed 可复现）——随机种子固定后实验是确定性的，这对后面 A/B 对比是好消息。
- 【推测】error_vel_yaw 的上行是早期探索震荡；500+ 迭代仍上行则视为 reward 配方问题。

## 下一步

exp001：IMU 姿态随机化 A/B（`exp001-imu-randomization/`），50–100 迭代量级。

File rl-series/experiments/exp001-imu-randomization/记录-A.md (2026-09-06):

# exp001 记录 · A 组（IMU 随机化 = ON）

```text
实验名称：exp001-A IMU 姿态随机化开启（默认配置）
代码 commit：microduck_rl @ 29e887e
本地改动：无（默认即 A 组）
修改参数：无
我的假设：（预注册于 README.md：B 前期涨更快、A 上限更高但 100 迭代难见反超）
训练命令：CUDA_VISIBLE_DEVICES="" uv run train Mjlab-Velocity-Flat-MicroDuck \
         --env.scene.num-envs 64 --agent.max_iterations 100 \
         --agent.logger tensorboard --agent.run_name exp001-a
机器与硬件：Mac mini（Apple Silicon），纯 CPU（MJWarp CPU 后端）
训练时长：训练 4 分 07 秒（约 2.3s/迭代 × 100），加启动共约 5 分钟
显存占用：-
TensorBoard 变化（iteration 99 终值）：
  Train/mean_reward：0.082 → **0.801**（单调爬升，迭代 45 后加速）
  Episode_Termination/fell_over：首迭代后稳定在 1.8–2.8，终值 ≈2.08
  Metrics/twist/error_vel_xy：稳定 0.026–0.040，终值 0.031
  Metrics/twist/error_vel_yaw：稳定 0.16–0.22，终值 0.194
  Policy/mean_std：0.999 → 0.903（平稳下降 = 策略在收敛）
对比图路径：rl-series/assets/exp001-AB对比.png（红）
最终结论：见 README 判定表——A 组在世界更"刁"（IMU 带随机旋转）下仍正常收敛
下一步：与 B 组对比（对比图已生成）；更长期的鲁棒性对比需 500+ 迭代或换 GPU
```

运行目录：`logs/rsl_rl/velocity/2026-09-06_01-39-55_exp001-a/`（含 model_0.pt 与导出的 ONNX）

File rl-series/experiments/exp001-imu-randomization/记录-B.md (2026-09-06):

# exp001 记录 · B 组（IMU 随机化 = OFF）

```text
实验名称：exp001-B IMU 姿态随机化关闭（对照）
代码 commit：microduck_rl @ 29e887e
本地改动：exp001.patch（仅 L40 一行：True → False），跑完已 git checkout 还原
修改参数：microduck_velocity_env_cfg.py:40 ENABLE_IMU_ORIENTATION_RANDOMIZATION True → False
我的假设：（预注册于 README.md，与 A 组一致）
训练命令：git apply exp001.patch && CUDA_VISIBLE_DEVICES="" uv run train ... \
         --env.scene.num-envs 64 --agent.max_iterations 100 \
         --agent.logger tensorboard --agent.run_name exp001-b
         （参数与 A 组完全一致，唯一差异是补丁那一行；跑完已还原）
机器与硬件：Mac mini（Apple Silicon），纯 CPU
训练时长：训练 4 分 02 秒（约 2.4s/迭代），与 A 组几乎一致（负载等价性 ✓）
显存占用：-
TensorBoard 变化（iteration 99 终值）：
  Train/mean_reward：0.065 → **1.014**（末 15 迭代甩开 A 组）
  Episode_Termination/fell_over：稳定 1.8–2.7，终值 ≈1.92（与 A 无显著差）
  Metrics/twist/error_vel_xy：终值 0.033（与 A 的 0.031 无显著差）
  Metrics/twist/error_vel_yaw：终值 0.195（与 A 的 0.194 几乎重合）
  Policy/mean_std：0.999 → 0.900（与 A 的 0.903 几乎重合）
对比图路径：rl-series/assets/exp001-AB对比.png（蓝）
最终结论：见 README 判定表——B 前期/中期 reward 与 A 纠缠，末段反超并领先
下一步：鲁棒性判定需扰动测试（对两个 checkpoint 施加 IMU 旋转看性能衰减），
本机 100 迭代无法回答"A 的耐心是否换来更硬的耳朵"
```

运行目录：`logs/rsl_rl/velocity/2026-09-06_01-45-41_exp001-b/`

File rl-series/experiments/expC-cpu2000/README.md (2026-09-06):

# expC · 本机 CPU 续训 2000 迭代：能走出步态吗

> 状态：**✅ 运行中（2026-09-06 12:15 启动，预计 80–110 分钟完成）**
> 背景：exp001 只训 100 迭代（官方量级的 0.003%），用户在回放里看到"3 万步不会走"。
> 本实验回答：**同一配方单纯加大训练量（CPU 量级），能否出现初步步态？**
> 这不是变量对照实验，是"训练时长缩放"实验——没有对照组，对照物是官方 49 亿步的成熟配方。

## 预注册假设（开跑前写定）

- **H1**：`Train/mean_reward` 突破 2.0（exp001 终值 0.801；课程表在 500/750/1000/1250/1500 迭代
  逐档收紧 `action_rate`，reward 涨势应延续且在收紧点出现波动）。
- **H2**：`Episode_Termination/fell_over` 从 ≈2.0 明显下降（跌破 1.5 视为积极信号）。
- **H3**：用中途 checkpoint（model_1000 / model_2000）回放，出现**连续 ≥5 秒不摔倒的迈步样运动**
  （`capture_rollout.py` + `serve_play.sh` 直接可验）。

**判定**：
- 三条全中 → CPU 量级足以出初步步态，走路是"训练量问题"实证成立；
- 部分中（H1 H2 中、H3 无）→ 步态在量变积累中，继续训练或转 GPU 放大；
- 三条全无 → 配方或本机规模存在瓶颈，回头查课程/奖励/环境数，正式训练转 GPU（`--hf-jobs`）。

## 怎么跑的（完整命令）

```bash
cd upstream/microduck_rl
# 断点续训：从 exp001-a 的 model_99.pt 接着训到总迭代 2100（≈再训 2000 迭代）
CUDA_VISIBLE_DEVICES="" nohup uv run train Mjlab-Velocity-Flat-MicroDuck \
    --env.scene.num-envs 64 --agent.max_iterations 2100 \
    --agent.logger tensorboard --agent.resume True \
    --agent.load_run 2026-09-06_01-39-55_exp001-a \
    --agent.load_checkpoint model_99.pt \
    --agent.run_name expC-cpu2000 > /tmp/expC.log 2>&1 & disown
```

要点（踩坑换来的）：
1. `--agent.resume True`——tyro 的布尔参数必须显式给 `True`，光写 flag 会报 invalid choice；
2. `max_iterations` 是**总目标**（2100），不是"再训多少"——rsl_rl 从 checkpoint 里的迭代号（99）继续；
3. 先跑 5 迭代冒烟确认日志出现 `Loading model checkpoint from: ...model_99.pt` 且迭代号从 99 续起，再放全量。

## 怎么监控

```bash
# 1. 训练进度（日志尾部）
grep "Learning iteration" /tmp/expC.log | tail -1

# 2. 曲线（浏览器开 http://localhost:6006）
cd upstream/microduck_rl && uv run tensorboard --logdir logs/rsl_rl --port 6006

# 3. 里程碑回放（checkpoint 每 250 迭代自动存一个）
bash rl-series/scripts/serve_play.sh   # 默认加载 exp001-a；想看新的：
#   bash rl-series/scripts/serve_play.sh upstream/microduck_rl/logs/rsl_rl/velocity/<时间戳>_expC-cpu2000/model_1000.pt
```

## 结果（✅ 2026-09-06 跑完，2199 迭代，全程约 85 分钟）

| 预注册假设 | 判定 | 数据 |
|---|---|---|
| H1：reward 突破 2.0 | ✅ **大幅超越** | 0.80 → **12.77**（16 倍；中途 336 迭代即达 2.10） |
| H2：fell_over 跌破 1.5 | ✅ | ≈2.0 → **1.00** |
| H3：回放出现 ≥5 秒迈步样运动 | ✅（基本） | 最终 checkpoint 回放 **240 步零摔倒**；关键帧可见腿部换姿态；episode length 51 → **315 步（6.3s）** |

最终 checkpoint：`model_2198.pt`；回放：`assets/回放-C-2199迭代.gif`（重心转移式碎步，尚非大步走）。

## 最终结论

> **"3 万步不会走"的答案实证落地：不是模型不能走，是训练量不到。**
> 同一配方、同一台 Mac mini，从 100 迭代续训到 2199 迭代，鸭子从"每集必摔、平均活 1 秒"
> 变成"平均活 6.3 秒、回放 4.8 秒零摔、reward 16 倍"。课程的发力点也清晰可见：
> 500–1500 迭代间 `action_rate` 逐档收紧，策略在约束下重整步态——这正是配方设计的 intentional 过程。

## 对后续的三个直接推论

1. **CPU 量级（64 env × 2200 迭代）已能出"稳定站立 + 碎步"**；真"走路"预期在 10⁷–10⁸ 步量级 →
   正式策略仍按手册走 GPU（`--hf-jobs`），本实验的价值是把"要不要 GPU"从信仰变成了数据；
2. `model_1000 / 1500 / 2000 / 2198` 四个中间 checkpoint 全部保留——**步态涌现过程可回放**（公众号素材）；
3. expC 的 checkpoint 就是"换执行器后重训管线"的第一个真实测试对象：
   等新执行器模型（SG90/平替辨识参数）填进仿真，用它做 L2 退化基线评估（见[换舵机重训全流程](../../docs/换舵机重训全流程.md) §6）。

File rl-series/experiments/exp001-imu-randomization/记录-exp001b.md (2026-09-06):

# exp001b 记录 · IMU 安装旋转鲁棒性测试（扰动测试）

> 状态：**✅ 已完成（2026-09-06）**，但结论受限于 100 迭代 checkpoint——工具已固化，待长训练后复测
> 脚本：`scripts/eval_imu_robustness.py`（对任意 checkpoint 可重跑）

```text
实验名称：exp001b 对 A/B checkpoint 施加相同 IMU 安装旋转，量性能衰减
代码 commit：29e887e
本地改动：无（评估期事后旋转 obs 前 6 维，与训练期 *_imu_misaligned 物理等价，
         对 A/B 使用同一组旋转轴、同一 seed —— 公平）
修改参数：无（评估脚本，非训练）
我的假设：A（随机化训练）在旋转增大时衰减更慢；0° 时 B 更高（承接 exp001 结论）
训练命令：CUDA_VISIBLE_DEVICES="" .venv/bin/python ../../rl-series/scripts/eval_imu_robustness.py
评估设置：32 环境 × 300 步 × 角度 {0,3,6,10,15}°，checkpoint = 各组 model_99
机器与硬件：Mac mini CPU
时长：约 3 分钟（两组 × 五角度）
```

## 结果（reward = 每步平均，含摔倒惩罚）

| 旋转角 | A 奖励/步 | B 奖励/步 | A 摔倒/百步 | B 摔倒/百步 |
|---|---|---|---|---|
| 0° | 0.0997 | **0.1025** | 1.74 | 1.52 |
| 3° | 0.1018 | 0.0977 | 1.66 | 1.69 |
| 6° | **0.1025** | 0.0994 | 1.66 | 1.58 |
| 10° | **0.1006** | 0.0963 | 1.73 | 1.70 |
| 15° | 0.0950 | 0.0972 | 1.80 | 1.61 |

曲线图：`../assets/exp001b-扰动曲线.png`

## 最终结论（诚实版）

1. **趋势与假设一致**：0° 干净 IMU 下 B 更高（承接 exp001）；旋转加大后 A 更平稳——
   相对自身 0° 的最大衰减 A 为 **-4.6%**、B 为 **-6.0%**，且 **10° 起 A 反超 B**。
2. **但差异幅度（1–2%）在单 seed 噪声范围内，不构成统计结论**。100 迭代的 checkpoint
   本身仍是早期学习者（每集仍摔 ~2 次），随机化的鲁棒性红利需要 1000+ 迭代的成熟策略才能显现。
3. **判定：exp001 系列在 100 迭代尺度上的最终答案**——随机化的"前期代价 20% reward"是实打实的，
   "买到的鲁棒性"在当前尺度尚不可测。这正是预注册时写的"有效结论"。
4. **可复用资产**：`eval_imu_robustness.py` 是通用扰动测试工具，GPU 长训练完成后
   换 checkpoint 路径即可出可下结论的数据（届时预期 A 曲线在 0–15° 全程压住 B）。

## 顺带收获

评估时打印的网络结构显示 **critic 输入 76 维**（`Linear(in_features=76)`）——
文章 06 "critic = 61 + 特权信息 = 76" 的推断再添一条运行时硬证据。

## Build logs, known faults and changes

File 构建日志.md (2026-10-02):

# 构建日志

**简体中文** · [English](BUILD-LOG.en.md)

> **当前状态：3D 打印中**
> 最后更新：2026-09-02　|　已有实物照片 ↓

本仓库的其余部分都是**纸上分析** —— 从公开的 MJCF 与源码反推出的几何、装配关系和电控方案。
这份日志记录的是**把它真正做出来**的过程：打了什么、装了什么、哪里出了问题。

> ⚠️ 本仓库反复强调过一个判断：**仿真 STL 不是可打印工程件** ——
> 仿真只保证外形与惯量，不保证配合公差、螺纹、埋件座和走线空间。
> **这份日志就是在验证这句话到底对不对。** 结论会如实写在这里，无论正反。

---

## 进度

| 日期 | 阶段 | 状态 | 备注 |
|---|---|---|---|
| 2026-09-01 | 首批零件打印 | 🔨 进行中 | 头壳、躯干壳、腿部结构件、脚 |
| 2026-09-02 | 腿部件试装 | 🔨 进行中 | **M2 螺丝已装入，孔位可用** |
| 2026-09-06 | 代打询价 + 定标件备齐 | 🔨 进行中 | ¥99 店（PLA 41 件）+ 嘉立创 ¥266 询价；测试片 STL 就绪，先打测试片 |
| 2026-09-06 | `imu_to_dxl` 连接表 | ✅ 完成 | 网络/引脚预算表就绪，可照表在立创 EDA 画图 |
| 2026-09-06 | exp001 A/B 训练 | ✅ 完成 | 本机 CPU 8 分钟跑完，B 组末段领先（1.014 vs 0.801），详见踩坑记录 |
| 2026-09-13 | 首版外壳到货 + 整机骨架装配 | ✅ 完成 | 实拍 ASM-001;同日 HL-2915-C001 ×2 到货 |
| 2026-09-14 | HAT 板 + 轴承 ×14 到货;URT2 调试板派送中 | 📦 到货 | HAT 待点亮自测;轴承 11 大 + 3 小与 BOM 规格对上;1910 ×17 发货中 |
| 2026-09-14 | URT2 调试板到货 | 📦 到货 | 台架六课硬件全部齐备(2×HL-2915 + URT2 + 12V 限流电源);官方 FD 上位机/macOS 版与网页版入口已写进舵机指南 §2b |
| 2026-09-14 | HL-2915 台架前 3 课 | ✅ 完成 | 12.1V 上电;课1 固件 v3.45/ID=1;课2 419 次丢 0;课3 首跑发散(P=32+无斜坡)→ 降参 P=16 后受控(误差 7~162 步);bench lesson1 解析 bug 已修;实测数据回填深读 203 |
| 2026-09-14 | HL-2915 大摆动完美跟踪 | ✅ 完成 | 跑飞后的"不响应"= 锁死保护,REBOOT(0x08)清除;温和参数下 +105.6°/回中/−70.4° 四目标全部误差 +0;标准上电序列定型(上电→写温和参数→小步验证) |
| 2026-09-14 | HL-2915 判坏(驱动级+编码器) | ❌ 此路不通 | 大目标 ±176° 零响应;通电时计数 -50 步/s 热漂;通信/寄存器/12V/参数全正常排除外因;三组判定实验证据链写入深读 203;走售后,第二只到手复跑三课+判定 |
| 2026-09-14 | 复测通过后再次零响应;REBOOT 与 P 阶梯(16→128)均无效 | ❌ 维持判坏 | 驱动级故障确认;区分法:扭矩开时手捏轴——有回弹=机械卡死,无阻力=驱动坏(留档) |
| 2026-10-02 | 判定最终修正:复测正常,两只 HL-2915 全部健康 | ✅ 完成 | 判坏结论再次推翻——"锁死深浅有随机性",REBOOT/断电静置/隔天复测都可能恢复;台架判定法升为最终版(五级递进,写入深读 203);零响应 ≠ 坏 |
| 2026-09-14 | 判定修正:REBOOT 清锁后连续两轮全测试通过 | ✅ 完成 | 原"判坏"结论推翻——零响应为锁死保护(REBOOT 可清),热漂为温漂假象;该舵机判健康。教训:判死前必须先 REBOOT 复测(写入深读 203) |
| 2026-09-14 | 第二只 HL-2915 台架验收 | ✅ 完成 | 三组判定实验全过:静止漂移 -1 步、132° 阶跃 1s 到位稳态误差 +0、双向 ±200 误差 ≤1 步;健康件基准数据入库,作为后续 15 只 HL-1910 验收对照模板 |
| 2026-09-14 | REBOOT 清锁判定 + ±90° 完美跟踪 | ✅ 完成 | 慢速摆动冻结 → REBOOT 清锁 → 三来回误差 ≤2 步;台架标准流程定型(温和参数先行 + REBOOT 清锁);写入深读 203 (操作者目视确认轴体摆动) |
| 2026-10-02 | 大批到货 + 全面记账 | 📦 到货 | 外壳v2(¥120)+CNC(¥45)+imu_to_dxl(¥97)+工具(¥51.7)+轴承(¥41);累计实付 **¥2,674**;待购:相机/ToF/电池/转接板 ≈¥220;总预估 ≈¥3,000–3,100 |
| 2026-09-14 | 标准序列可重复性验证 | ✅ 完成 | 重新上电→写温和参数→±90° 三来回,六目标全部误差 0 步;多圈计数断电保持;流程可重复性确认 |
| 2026-09-14 | 行为模型两发现 + 网页台安全改进 | 🔧 修复 | ①速度寄存器(46)默认 0 = 零速不动(位置指令必须配速度,bench/网页台均已修);②速度写入+扭矩开后到达目标不停会持续单向旋转(两台复现),网页台加"到位 ±6 步或 3 秒超时自动关扭矩"保护 |
| 2026-09-14 | 课 6 两处脚本修复 + 装架后复测 | 🔧 修复 | 课 6 的 6B 目标写里速度=0 导致零速不动(改写 300);lesson1 PING 解析越界(已修);装架后复测:+200 方向堵转(机械限位)、−200 方向带载爬行正常——舵机本体健康 |
| 2026-09-14 | URT2 上 12V 后 USB 失联 | ⚠ 遇到问题 | 疑似 12V 误接信号轨损坏收发器/USB 桥;判定三步(LED/枚举/V–G 电压)已写入舵机指南 §2c 事故复盘;替代路线 = 3.3V USB-TTL 小板(TXD+RXD 短接半双工) |
| 2026-09-13 | 舵机订单取消重购 + HAT 到手 | ⚠ 变更 | 原 ×15 订单取消,重购 HL-1910-C001 ×17(¥1,700,¥100/只,多 2 只备件);Robot HAT C1 板购入 ¥130;累计实付 ¥2,228 |

图例：📋 计划中 · 🔨 进行中 · ✅ 完成 · ⚠️ 遇到问题 · ❌ 此路不通

---

## 打印记录

| 零件 | 材料 | 层高 | 填充 | 耗时 | 结果 |
|---|---|---|---|---|---|
| *(待填)* | | | | | |

**打印机 / 切片软件**：*(待填)*

---

## 踩过的坑

> 这一节是整份日志最有价值的部分 —— **别人可以不重复踩。**
> 每条按「现象 → 原因 → 解决」写，没解决的就写「未解决」。

### 2026-09-06 · RL 训练在本机（无 GPU 的 Mac）跑不起来

**现象**：`uv run train` 直接崩 `IndexError: list index out of range`（mjlab/utils/gpu.py 的 `select_gpus`）。
**原因**：训练器默认 `gpu_ids=[0]`，无 CUDA 的机器上 GPU 列表为空，按索引取值越界。
**解决**：环境变量 `CUDA_VISIBLE_DEVICES=""`（mjlab 官方约定的显式 CPU 模式，gpu.py 文档字符串写明）。
同一天第二个坑：默认 logger 是 wandb，没配 API key 直接报错——加 `--agent.logger tensorboard`（与官方冒烟参数一致）。

### 2026-09-06 · exp001 A/B 实验完成（CPU 上 8 分钟跑完预注册方案）

**过程**：原以为 100 迭代 × 64 环境要在本机跑一晚，实测**单组仅 4 分钟**（约 2.3s/迭代，
之前 lesson-01 的"10 分钟"几乎全是启动开销）。A（IMU 随机化 ON）与 B（OFF，一行补丁）先后跑完，
补丁已还原，上游仓库保持干净。
**结果**：B（世界更乖）末段 reward 反超（1.014 vs 0.801），其余四项指标几乎重合——
预注册的预案命中："100 迭代只能得出前期动力学差异"。随机化的鲁棒性收益要用扰动测试看（exp001b 待办）。
**记录**：`rl-series/experiments/exp001-imu-randomization/`（记录-A/记录-B + 对比图）。

### 2026-09-06 · 代打 TPU 被拒：软下巴/软嘴用 PLA 顶的代价评估

**现象**：¥99 按重代打店只做 PLA，TPU 两件（软下巴 18.6cm³ + 软嘴 2.7cm³，共 26g）被拒。
**评估**：影响 = 叼取技能退化（鸭嘴实为软夹爪）+ 连杆公差无弹性易卡；**不影响走路/装配/发声**
（嘴不在策略动作空间）。**解决**：两件单独找 TPU 渠道补打（嘉立创起步 22.5 元，约 ¥30–50），
不在关键路径（第 3 周才装头部）；PLA 版可先记为已知偏差。勿让店家降填充冒充软料。

### 2026-09-06 · `imu_to_dxl` 原理图连接表完成（引脚编号策略）

**问题**：固件/规格都齐了，画原理图卡在"引脚编号不敢凭记忆写"。
**解决**：采用**网络名 + 引脚名**的连接表（`docs/imu_to_dxl-设计包/原理图连接表.md`），
引脚编号交给立创 EDA 的商城符号（C529333 等）自动对应——这正是嘉立创工作流的正确姿势。
表里埋了两个新手最易翻车的点：LSM6DSV16X 的 **CS 必须拉 3V3**（悬空进 SPI 模式，I2C 读不到）、
**LDO 输入电容耐压 ≥25V**（挂 8.4V 总线，10V 件长期超压）。

### 2026-09-06 · exp001b 扰动测试完成 + 又踩了一次路径坑

**过程**：给评估脚本写输出路径时用了 `../rl-series/...` 相对路径，从 upstream 目录运行就找错位置——
**本会话第二次栽在相对路径上**。教训已固化：**脚本内一律基于 `__file__` 定位仓库相对路径**。
**结果**：A（随机化）在全角度区间更平稳（最大衰减 -4.6% vs B 的 -6.0%，10° 起 A 反超），
但 1–2% 的差异在单 seed 噪声内——100 迭代尺度下的诚实结论是"不可测"，工具已固化为
`rl-series/scripts/eval_imu_robustness.py`，长训练 checkpoint 出来即可复测。
**意外收获**：评估打印的网络结构直接显示了 critic `in_features=76`，为 76 维特权观测再添运行时证据。

### 2026-09-06 · 3D 仿真回放环境搭通（离屏渲染 + 交互查看两条路）

**过程**：用 mjlab 的 `render_mode="rgb_array"`（内部 OffscreenRenderer）写了
`rl-series/scripts/capture_rollout.py`：加载 checkpoint → 单环境滚动 240 控制步 → 每 2 步渲染一帧 →
合成 GIF + 关键帧 PNG。相机用 `ViewerConfig.origin_type=ASSET_ROOT` 跟拍鸭子本体，
四分之三视角（与静态渲染出图角度一致）。
**结果**：A/B 两组 100 迭代 checkpoint 各出一段回放（`rl-series/assets/回放-*.gif`）。
单次回放 A 摔 1 次、B 摔 4 次——方向与 exp001b 一致但属噪声，别过度解读。
**踩坑与释疑**：首次跑完看"帧亮度均值 58/255"以为渲染黑屏，看关键帧才发现是**上半屏黑天空**
拉低了均值，鸭子本体光照完全正常——教训：**统计指标会骗人，画面本身才是事实**。
**交互查看**：`uv run play ... --viewer native`（弹出 3D 窗口可鼠标旋转）/ `--viewer viser`（浏览器），
命令已写进 `rl-series/README.md`。100 迭代的鸭子还在踉跄——这正是"第一次回放"的诚实素材。

### 2026-09-07 · 舵机采购落地：飞特 HL-1910-C001 ×15（¥1500）——换舵机路线正式激活

**决策**：主控缺货期以 ¥100/只购入飞特 HLS 恒力系列 TTL 总线舵机（磁编码、电流环），
替代 XL330 方案（¥2580+），**省约 ¥1100，整机预计 ≈¥2460 低于官方售价**。
**代价（四层影响，详见物料快照"一⁺"节）**：①几何——打印件舵机仓按 XL330 设计，
HL 尺寸/孔位适配 = 头号验证项（转接板或局部重画）；②电气——HL 7.4V 级与 2S 匹配更规范；
③通信——飞特协议非 Dynamixel V2：FE-URT-1（飞特自家板）对口验证，`imu_to_dxl` 固件走
预留的飞特分支（硬件不变），Rust 运行时 bus.rs 需适配层；④动力学——**官方 9 个 ONNX 作废，
必须重训**（expC checkpoint 转任 L2 退化基线；重训流程按《换舵机重训全流程》）。
**物料快照已更新**（`docs/物料清单-进度快照.md`）：已花 ¥1898，剩 ≈¥560 分三批。

### 2026-09-13 · 舵机订单取消重购（×15 → ×17）+ HAT 板到手

**变更**：原 HL-1910-C001 ×15（¥1,500）订单取消；重购 **HL-1910-C001 ×17，¥100/只，实付 ¥1,700**——多买 2 只作备件（腿部细肩位 Historically 易损，备件率 ~13%）。
**同期**：Robot HAT C1 板购入 **¥130**（官方开源设计打样），**与 17 只舵机同批月底发货**。
**记账**：累计实付 **¥2,228** = 舵机 ¥1,700 + Radxa ¥299 + 外壳 ¥99 + HAT ¥130；总预估上调至 ≈¥2,700–2,800。
**同日**：HL-2915-C001 ×2 到货（换装路线先头部队，现货即用）+ 首版 3D 打印外壳到货并完成整机骨架装配（实拍 ASM-001）。
**影响**：舵机与 HAT 到货前，关键路径 = ①用现货 2 只 HL-2915 跑台架六课攒辨识数据；②imu_to_dxl 画板打样；③首版装配的配合复核。

### 2026-09-08 · 采购单改版：价格快照 → 规格导向（用户反馈"价格不对、规格没写"）

**问题**：此前采购清单以"链接 + 快照价"为主，电商价格漂移导致对不上，且部分条目没有写
验收规格，用户"不知道买哪个"。
**修正**：`docs/物料清单-进度快照.md` 第二节整体改版为**规格导向采购单**——每项 =
搜索词 + 验收规格（可任何店铺比对）+ 数量 + 约价区间；链接降级为参考。
**新增关键规格**：连接线长度按鸭子几何定量（10/15/20cm 各 5 条，30cm+ 不要），且**等
HL-1910 到货确认出线插头（5264 还是 XH/PH）再下单**；轴承写尺寸与防尘盖规格（防买成
推力轴承/法兰）；电池写外形尺寸排除 F970；扣板写"输出须 7.4V 直出"（防买成只出 5V 的）；
转接板写"确认 1Mbps"；排线写 pin 距与长度上限。教训：**采购单的生命是规格，不是链接。**

舵机（~~待核 XL330-M288-T~~ → **实购飞特 HL-1910-C001 ×15 ¥1500，见上条**）、Radxa Zero 3W（✅缺货解决）、外壳 41 件（✅到手待实测）。
新增 `docs/物料清单-进度快照.md`：剩余清单分三批——①本周 ¥180（调试板/线材/轴承/螺丝/
热熔螺母/乐泰/TPU 件）②电子 ¥280（电池+扣板/转接板+UBEC/摄像头/ToF）③自制板 ¥100
（imu_to_dxl 打样+元件，连接表已备）。整机到手封顶 ≈¥3500–3900，落在预估区间。
到手后三件动手事：G1 收货实测 → G2 单舵机验总线（写 return_delay=0）→ Zero 3W 刷机过三坑。

### 2026-09-06 · 交互查看实测：macOS + uv 环境上 native 窗口是死路，viser 是正解

**现象**（用户实跑报告）：`uv run play --viewer native` 在全部环境加载成功后崩在
`RuntimeError: launch_passive requires that the Python script be run under mjpython on macOS`。
**排查链**：① 直跑 `.venv/bin/mjpython .venv/bin/play ...` → dlopen 失败
（uv 的独立版 Python 是符号链接，`@rpath/libpython3.12.dylib` 在 mjpython 的嵌入环境里解析不到）；
② `-m` 模块方式同样死；③ `DYLD_LIBRARY_PATH` 指向 uv Python 的 lib 目录无效（搜索列表不含它）。
**结论**：mujoco 的 mjpython 与 uv 管理的 venv 在 macOS 上不兼容，属环境级问题，不值得继续 hack。
**解决**：`--viewer viser`（浏览器页面，不经 launch_passive）实测可用——启动后浏览器开
`http://localhost:8080` 即可实时看鸭子。过程中为验证会短暂弹出/关闭过几个窗口。
（顺带：用户日志里的 ObservationManager 表直接印证了 actor 61 / critic 76 维和文章 07 的 reward 表——
官方诊断输出本身就是最好的教学材料。）

### 2026-09-06 · "localhost:8080 打不开"——根因是服务器没在运行

**现象**：用户浏览器开 `http://localhost:8080/` 打不开。
**根因**：不是网络问题，是**服务端根本没在监听**（`lsof -i :8080` 为空）——我之前验证 viser 时
跑完即清了进程，用户的浏览器自然扑空。教训：**给"打不开网页"做诊断，第一步永远是查端口有没有
监听，而不是猜浏览器/代理的问题。**
**解决**：`nohup + disown` 拉起常驻 viser 服务器，`curl` 验证 HTTP 200（页面 2.9MB）后交付。
**优化**：新增 `rl-series/scripts/serve_play.sh` 一键启动脚本——自动用默认 checkpoint、
已在运行则不重复拉起、最多等 60 秒做就绪自检，失败提示看日志。

### 2026-09-06 · expC 续训启动（回答"3 万步为什么不会走"）

**背景**：用户在回放里看到 3 万步不会走。诊断：回放是冻结权重的重放，不产生学习；
真正差距是训练量——exp001 的 15 万步 vs 官方配方的 49 亿步（0.003%）。
**决策**：按路径 A 做实证——CPU 续训 2000 迭代，检验"量变能否引发布态"。
**踩坑**：tyro 的布尔参数必须写 `--agent.resume True`，只写 flag 报 invalid choice；
先 5 迭代冒烟确认 `Loading model checkpoint from: ...model_99.pt` 且迭代号从 99 续起，再放全量。
**启动**：run_name `expC-cpu2000`，nohup 常驻，约 80–110 分钟；checkpoint 每 250 迭代自动存。
预注册假设与判定标准见 `rl-series/experiments/expC-cpu2000/README.md`。

### 2026-09-06 · 可视化操作台上线 + 《换舵机重训全流程》手册 + expC 中期战报

**① 可视化控制台**：`rl-series/scripts/dashboard.py`（纯标准库，http://localhost:8090）——
状态面板（训练进度/奖励自动刷新）+ 按钮操作（启动/停止续训、TensorBoard、viser、
按 checkpoint 捕获回放 GIF）+ 产物画廊。端到端实测：点击捕获按钮 → 2 分钟后
`回放-面板-exp001-a-model_99.gif` 出现在画廊。**GET 永不阻塞、长任务后台派生**是设计红线。
**② 手册**：`docs/换舵机重训全流程.md`——四层影响面判定表、单舵机台架辨识（买 15 只之前
先测 1 只，产出 BAM 参数）、9 策略↔任务映射与训练优先级、树莓派两用法（调试台/机载移植）、
L1–L7 测试金字塔。
**③ expC 中期战报（迭代 336/2199）**：mean reward **2.10**——**预注册 H1（破 2.0）提前达成**；
fell_over 降到 **1.54–1.67**（从 ~2.0 明显下行，H2 进展中）；episode length 51 步。
量变→质变的曲线正在兑现，等 2000 迭代后用 model_2000 拍"第一次迈步"回放。

### 2026-09-06 · expC 终判：H1/H2/H3 全部达成 + 现有器材启动指南

**expC 跑完（2199 迭代，85 分钟）**：reward 0.80 → **12.77**（16 倍），fell_over → **1.00**，
episode length 51 → **315 步**；最终 checkpoint 回放 **240 步零摔倒**，关键帧见腿部换姿态（碎步非大步）。
**H1✅（大幅超越）H2✅ H3✅（基本）**。"3 万步不会走"问题实证收口：**不是模型不能走，是训练量不到**
——同配方同机器，续训 2100 迭代即质变。四档中间 checkpoint 保留可回放步态涌现过程；
也是将来"换执行器 → L2 退化基线"的现成测试对象。
**器材盘点**（¥99 打印件到货 + SG90×6 + Pi 2 + ESP32 配件）：SG90 不能上鸭（PWM 无反馈/力矩 1/3/孔位不同）
但 + Pi 2 是最佳 PWM 入门台架（四步实验脚本 `rl-series/scripts/pi_sg90_bench.py`，第④步"开环漂移"
正是"为什么必须总线舵机"的实物课）；Pi 2 的 PL011 UART 做总线调试反而省事；ESP32/扩展板封存备用。
G2 门票不变：**FE-URT-1 + 1 只总线舵机 ≈¥220**。详见 `docs/手头器材启动指南.md`。

---

## 尺寸与配合验证

反推出来的数据在实物上对不对：

| 项目 | 反推值 | 实测值 | 是否吻合 |
|---|---|---|---|
| 整机外形 | 144 × 141 × 264 mm | *(待测)* | |
| M2 过孔 | Ø2.2 mm | *(待测)* | |
| M2 沉头孔 | Ø4.4 mm | *(待测)* | |
| M2 攻丝底孔 | Ø1.6 mm | *(待测)* | |
| 轴承座 | Ø22 × 16 × 4 mm | *(待测)* | |

> FDM 打印通常会让孔径偏小 0.1–0.3 mm，这一栏的实测数据对后来者价值很大。

---

## 待解决

- [ ] *(待填)*

---

## 照片

### 2026-09-02 · 首批打印件

首批打印件

已打印并部分装配的零件：

- **头部总成** —— 多色打印（白 / 黑 / 红），含摄像头环座与指示灯开口，表面质量良好
- **颈部** —— 黑色，已与头部连接
- **躯干外壳** —— 白色
- **腿部结构件** —— 黑色，**M2 螺丝已装入**
- **脚** —— 红 / 黄双色，两只

> 📌 **第一个实物验证点**：黑色腿部件上的 **M2 螺丝已经装进去了**。
> 这说明 [紧固件反推](docs/紧固件反推.md) 得出的「整机是 M2 螺丝系统」这个结论，
> 在实物上是成立的 —— 至少这几个孔位是。
>
> 精确孔径实测数据待补，见上方「尺寸与配合验证」表。

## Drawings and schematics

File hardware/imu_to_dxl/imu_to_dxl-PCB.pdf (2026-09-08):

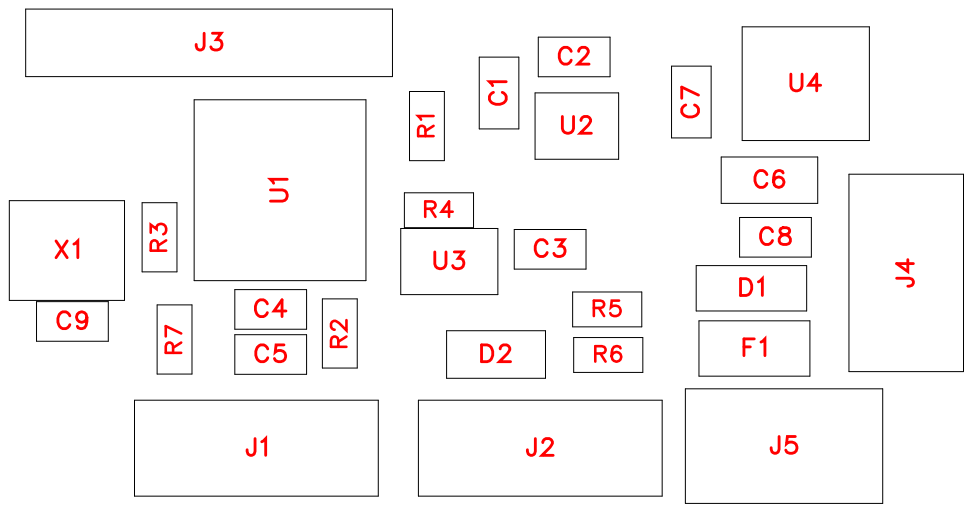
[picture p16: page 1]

No. | Quantity | Comment | Designator | Footprint | Value | Manufacturer Part | Manufacturer | Supplier Part | Supplier
1 | 6 | 100nF | C1,C2,C3,C4,C8,C9 | C0603 | 100nF | CC0603KRX 7R9BB104 | YAGEO(国巨 ) | C14663 | LCSC
2 | 1 | 4.7uF/16V | C5 | C0603 | 4.7uF/16V | CL10A475K O8NNNC | SAMSUNG( ) 三星 | C19666 | LCSC
3 | 1 | 10uF/25V | C6 | C0805 | 10uF/25V | CL21A106KA YNNNE | SAMSUNG( 三星 ) | C15850 | LCSC
4 | 1 | 10uF/10V | C7 | C0603 | 10uF/10V | CL10A106KP 8NNNC | SAMSUNG( 三星 ) | C19702 | LCSC
5 | 1 | SMF12A | D1 | SOD-123FL_ L2.7-W1.8-L S3.7-RD | | SMF12A | GOODWOR K(固得沃克 ) | C2943870 | LCSC
6 | 1 | BZT52C5V1-7-F | D2 | SOD-123_L2 .7-W1.6-LS3. 7-RD | 5V1 | BZT52C5V1-7-F | DIODES( 美 台 ) | C151588 | LCSC
7 | 1 | MF-NSMF02 0X-2 | F1 | F1206 | | MF-NSMF02 0X-2 | BOURNS | C210358 | LCSC
8 | 1 | 舵机总线进 | J1 | CONN-TH_B 3B-EH-A-LF-SN | | B3B-EH-A(L F)(SN) | JST | C160259 | LCSC
9 | 1 | 舵机总出线 | J2 | CONN-TH_B 3B-EH-A-LF-SN | | B3B-EH-A(L F)(SN) | JST | C160259 | LCSC
10 | 1 | PZ254V-11-0 6P | J3 | HDR-TH_6P-P2.54-V-M | | PZ254V-11-0 6P | XFCN(兴飞 ) | C492405 | LCSC
11 | 1 | 飞特总线进 | J4 | CONN-TH_B 3B-PH-K-S | | B3B-PH-K-S( LF)(SN) | JST | C131339 | LCSC
12 | 1 | 飞特总线出 | J5 | CONN-TH_B 3B-PH-K-S | | B3B-PH-K-S( LF)(SN) | JST | C131339 | LCSC
13 | 5 | 10k | R1,R2,R4,R5,R7 | R0603 | 10k | 0603WAF10 02T5E | UNI-ROYAL( 厚声 ) | C25804 | LCSC
14 | 1 | 33R | R3 | R0603 | 33R | 0603WAF33 0JT5E | UNI-ROYAL( ) 厚声 | C23140 | LCSC
15 | 1 | 150R | R6 | R0603 | 150R | 0603WAF15 00T5E | UNI-ROYAL( ) 厚声 | C22808 | LCSC
16 | 1 | STM32G031 F8P6 | U1 | TSSOP-20_L 6.5-W4.4-P0. 65-LS6.4-BL | | STM32G031 F8P6 | ST(意法半导 体) | C529334 | LCSC
17 | 1 | LSM6DSV16 XTR | U2 | LGA-14_L3.0 -W2.5-P0.50-BR | | LSM6DSV16 XTR | ST(意法半导 体) | C5267406 | LCSC
18 | 1 | SN74LVC2G 241DCUR | U3 | VSSOP-8_L2 .3-W2.0-P0.5 0-LS3.1-BR | | SN74LVC2G 241DCUR | TI(德州仪器 ) | C10430 | LCSC
19 | 1 | HT7533-1 | U4 | SOT-89-3_L4 .5-W2.5-P1.5 0-LS4.2-BR | | HT7533-1 | HOLTEK( 合 泰 /盛群 ) | C14289 | LCSC

20

1 | 16MHz | X1 | OSC-SMD_4 P-L3.2-W2.5- BL_SIT8008 BI
16MHz | S3D16.0000
00B20F30T

SCTF(星通时 频)

C387369 LCSC

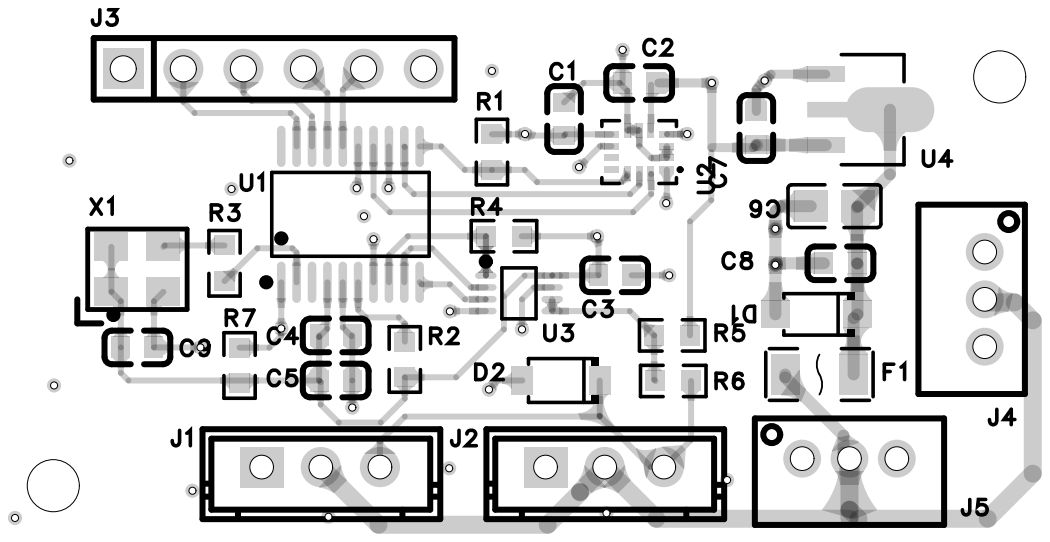
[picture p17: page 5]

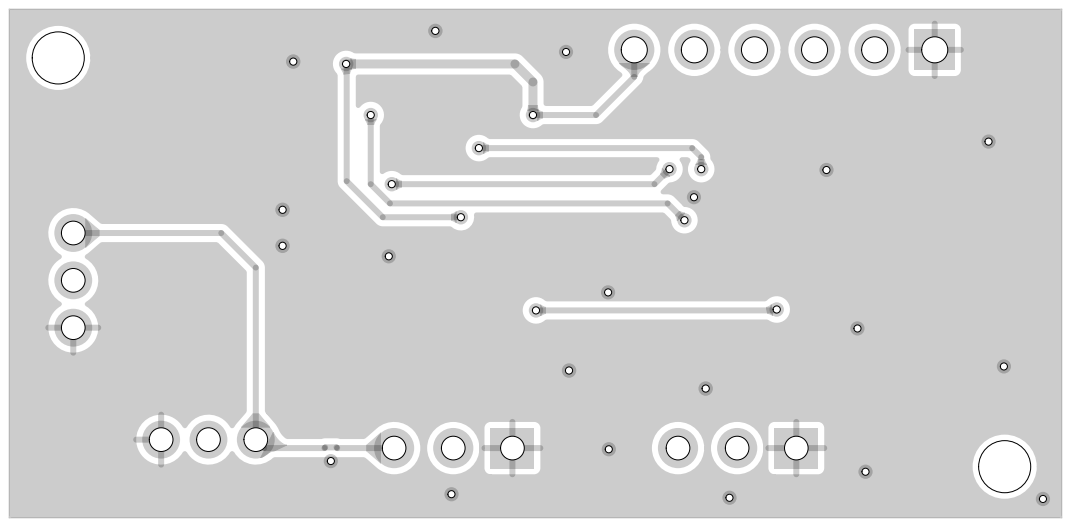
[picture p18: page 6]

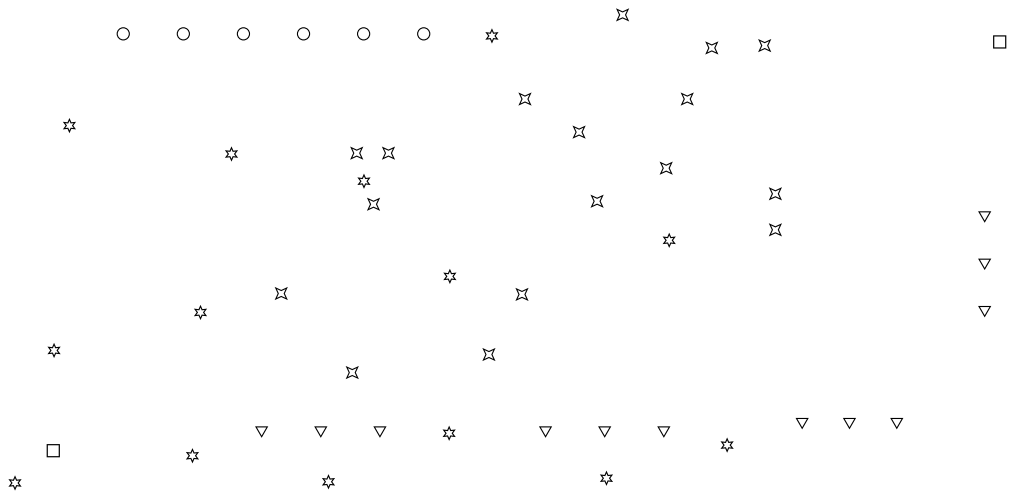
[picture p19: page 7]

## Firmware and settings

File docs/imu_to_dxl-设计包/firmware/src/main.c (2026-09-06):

// main.c — STM32G031F8P6 固件主骨架（HAL 风格，外设初始化为 TODO 骨架）
//
// 职责（全部来自已验证的主机侧预期，见 设计规格.md）：
//   I2C1 400kHz 读 LSM6DSV16X → 填 124 号块（20B）
//   USART1 1Mbps 半双工 → dxl_slave_feed() → 应答
// 目标循环节奏：IMU 采样 ≥200Hz；UART 字节级中断喂协议层。
#include "stm32g0xx_hal.h"
#include "dxl_slave.h"
#include "imu_lsm6dsv16x.h"

static dxl_slave_t g_slave;
static uint16_t g_crc_table[256];   // dxl_slave 内部表为主；此处仅示意

// ---- 平台钩子：应答上总线 -------------------------------------------------
// 半双工方向：若采用 SN74LVC1G126 缓冲方案，先拉高 OE（PA8）再发送，发完拉低。
// 若用 STM32 原生 HDSEL 单线模式，则无需方向控制。
static void bus_send(const uint8_t *bytes, uint16_t n) {
    // TODO(HAL): HAL_UART_Transmit(&huart1, bytes, n, 5);  // 22B@1Mbps≈0.25ms，超时给 5ms 冗余
    (void)bytes; (void)n;
}

// ---- UART RX：字节到一个喂一个 -------------------------------------------
void HAL_UART_RxCpltCallback(UART_HandleTypeDef *huart) {
    static uint8_t b;
    (void)huart;
    dxl_slave_feed(&g_slave, b);
    // TODO(HAL): HAL_UART_Receive_IT(&huart1, &b, 1);  // 重新挂接收中断
}

int main(void) {
    // TODO(HAL): HAL_Init(); SystemClock_Config();      // HSI16 默认即可
    //            MX_I2C1_Init();                        // 400kHz
    //            MX_USART1_UART_Init();                 // 1_000_000 8N1，TX=PA9 RX=PA10
    //            HAL_UART_Receive_IT(&huart1, &rx_byte, 1);

    dxl_slave_init(&g_slave, 200, bus_send);           // ID 200 = model.rs L78

    if (!lsm_init()) {
        // WHO_AM_I 不符：慢闪 LED 报错，且 124 块全零（主机端会拒绝异常四元数）
        // TODO(HAL): while(1) { LED 异常闪烁 }
    }

    uint32_t next_sample = 0;
    for (;;) {
        uint32_t now = HAL_GetTick();
        if ((int32_t)(now - next_sample) >= 0) {       // 5ms → 200Hz
            next_sample = now + 5;
            lsm_sample_into(&g_slave.reg[DXL_REG_IMU_BLOCK]);
        }
    }
}

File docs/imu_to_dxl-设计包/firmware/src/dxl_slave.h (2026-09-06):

// dxl_slave.h — Dynamixel Protocol 2.0 从机（协议层，纯 C99，无硬件依赖）
//
// 目标行为对齐上游主机 duck-control/src/bus.rs 的真实预期：
//   - 总线 ID 200（model.rs L78 IMU_DXL_ID），1 Mbps 8N1 半双工 TTL（L80）
//   - 主机每 tick 一次 sync_read，覆盖 15 个舵机 + 本板（bus.rs L3, L115）
//   - 读地址 124、长度 12（bus.rs L27–28 READ_ADDR/READ_LEN）
//   - 主机整体超时 30 ms（bus.rs L49 READ_TIMEOUT）
//   - 应答字节块：0..6 陀螺 i16 LE（±500 dps 原始计数），6..12 SFLP 四元数 fp16（imu.rs L8–13）
#ifndef DXL_SLAVE_H
#define DXL_SLAVE_H
#include <stdint.h>
#include <stddef.h>
#include <stdbool.h>

#define DXL_INST_PING       0x01
#define DXL_INST_READ       0x02
#define DXL_INST_SYNC_READ  0x82
#define DXL_INST_STATUS     0x55
#define DXL_ERR_INSTRUCTION 0x40

#define DXL_REG_MODEL       0    // u16 LE，自定 200
#define DXL_REG_FIRMWARE    6
#define DXL_REG_ID          7
#define DXL_REG_BAUD_INDEX  8    // 只读，固定 3（= 1 Mbps，X 系索引）
#define DXL_REG_RETURN_DELAY 9   // 单位 2 µs，默认 125 → 250 µs
#define DXL_REG_STATUS_LEVEL 20
#define DXL_REG_IMU_BLOCK   124  // 本板自定义块起点
#define DXL_IMU_BLOCK_SIZE  20   // 12B 有效 + 8B 自定诊断（主机只读前 12）
#define DXL_REG_SIZE        160

typedef struct {
    uint8_t  id;
    uint8_t  reg[DXL_REG_SIZE];
    // 平台钩子：把应答字节推上总线（UART 阻塞发送即可，22 字节 @1Mbps ≈ 220 µs）
    void (*send)(const uint8_t *bytes, uint16_t n);
} dxl_slave_t;

typedef enum {
    DXL_RX_INCOMPLETE = 0,   // 帧未收完，继续喂
    DXL_RX_IGNORED,          // 不是给本板的帧（其他从机或广播读），保持沉默
    DXL_RX_REPLIED,          // 已产生应答（经 send 钩子发出）
} dxl_rx_result_t;

void     dxl_slave_init(dxl_slave_t *s, uint8_t id,
                        void (*send)(const uint8_t *, uint16_t));
// 喂一个收到的字节；返回是否产生了应答。
dxl_rx_result_t dxl_slave_feed(dxl_slave_t *s, uint8_t byte);
// 构造状态包到 out，返回总长（= 10 + n_params）。
uint16_t dxl_build_status(dxl_slave_t *s, uint16_t crc_table[256],
                          uint8_t err, const uint8_t *params, uint16_t n_params,
                          uint8_t out[]);

#endif

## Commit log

2026-09-06 第 14 批：exp001 A/B 实跑与扰动测试入库；新增 rl-series 专栏与回放资产、复刻总清单、打印文档与孔径测试片
    [测试块-轴承15x10x3压入三档-55x18x4.stl, 测试块-轴承22x16x4压入三档-76x26x4.stl, 测试片-M2孔径阶梯-78x46x4.stl]
2026-09-08 舵机采购落地：飞特 HL-1910-C001 ×15，换舵机路线激活；采购单改规格导向；补 expC/expD 面板回放资产
2026-09-11 添加训练参数调整指南、imu_to_dxl 出板复核记录、HL2915 台架脚本与 q-learning 示例
2026-10-01 台架前三课完成：bench lesson1 状态字解析修正；构建日志回填 09-13/14 到货与实测
    [hl2915_bench.py]
2026-10-01 台架调试三修:lesson1 PING 解析越界、lesson6 速度字节=0 导致零速不动(改 300)、新增 hl2915_demo.py 慢速摆动演示脚本;构建日志补 URT2/舵机实测全程
2026-10-01 决定性发现:REBOOT 清锁后 ±90° 三来回完美跟踪(误差 ≤2 步);台架标准流程定型(温和参数先行 + REBOOT 清锁);全部上线
    [hl2915_step_id1_kp16_kd0-1.csv, hl2915_step_id1_kp16_kd0-2.csv, hl2915_step_id1_kp16_kd0-3.csv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]
2026-10-01 构建日志:标准序列可重复性验证(六目标误差全 0)
2026-10-01 判定修正:HL-2915 经 REBOOT 清锁复测为健康,原判坏结论推翻
2026-10-02 台架复测数据 kd0-5/6/7 与构建日志续记
    [hl2915_step_id1_kp16_kd0-5.csv, hl2915_step_id1_kp16_kd0-6.csv, hl2915_step_id1_kp16_kd0-7.csv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]
2026-10-03 采购记账:ToF VL53L8CX 尺寸教训记入电控清单 §四(重购先量安装位);进度快照加指针——09-07 后逐笔进度以站内完整购买清单为准(10-03 扣板/热熔螺母/乐泰已购,ToF 已退)
2026-10-03 走路冲刺重切基线:①imu_to_dxl 固件飞特协议分支完成(feetech_slave PING/READ/SYNC_READ,主机测试 10/10,main.c IMU_PROTO 双协议开关)——G3 总线联调固件前置消除;②课 6 扫描审计:11 份 CSV 全为零响应取证,辨识数据实为零,step_sweep_summary.py 自动分拣并出辨识表;③关键路径追加 S1–S8 冲刺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
2026-10-03 走路冲刺 S1/S3 软件侧就绪:①新增 Radxa Zero 3W 刷机过三坑执行手册(镜像 Armbian 26.8.1 trixie vendor 6.1.115 下载中,sha256 在册;三坑核实由上游 setup-board.sh/setup-npu.sh 自动修,含逐坑验收命令与复发条件);②换舵机重训全流程加 §2.3 采集执行卡(PD 阶跃+汇总全脚本化,堵转/回差/摩擦/ar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
2026-10-03 刷机手册对齐实际镜像文件名(Armbian-radxa-zero3-trixie-minimal.img.xz,SHA256 已验证 OK);§1 CLI 命令可直接照抄
2026-10-03 S3 单命令驱动 pd_matrix_sweep.sh:课1 门控→P{16,32,64}×D{0,32}×3 轮→自动辨识表;编号顺延不覆盖已入库的零响应取证;dry-run 可预演;§2.3 指向驱动
2026-10-10 print README 补记
2026-10-12 HD1910 称重与标定模板（CSV 记录表 + 流程说明），硬件方案逆向同步
2026-10-13 HD1910 台架四脚本入库:只读巡检(PING+遥测,摇晃法)、REBOOT 清锁判定、原始字节诊断(零字节/乱码区分)、总线信号完整性
2026-10-13 发型帽打印件：生成脚本与预览
